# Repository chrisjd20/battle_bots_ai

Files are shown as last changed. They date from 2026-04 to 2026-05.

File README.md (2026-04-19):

# battle_bots_ai

Monorepo for **Plastic Antweight** combat robots (about **1 lb / 454 g or less**) and related work aligned with **SPARC** (Standardized Procedures for the Advancement of Robotic Combat). It holds software, PCB design, mechanical/CAD, 3D-printed parts, and docs for **multiple** bots and battle-bot accessories—not a single project.

## PCB design

**KiCad** is used for all PCB work. Shared footprints/symbols can live under `shared/kicad-libraries/`; per-bot or per-accessory boards sit under `bots/<name>/` or `accessories/<name>/` (often in a `pcb/` subfolder as projects grow).

`launch.sh` can open a KiCad project when present (see script for the expected path).

## KiCad + AI setup

- MCP config: `.cursor/mcp.json` (server name `kicad`)
- Launcher: `./launch.sh` (auto-detects one project, or pass explicit `.kicad_pro`)
- Workflow guide: `docs/hardware-workflow.md`
- Fabrication output location: `fab/`

Quick commands (after a KiCad project exists):

```bash
./launch.sh --check path/to/project.kicad_pro
kicad-cli sch erc path/to/project.kicad_sch
kicad-cli pcb drc path/to/project.kicad_pcb
```

## Mechanical CAD + AI setup

- Primary tooling: `FreeCAD` (GUI) + `build123d`/`CadQuery` (Python source)
- CAD tool bootstrap: `./shared/software-tools/cad/bootstrap.sh`
- MCP config: `.cursor/mcp.json` (server name `cad`)
- CAD workflow notes: `shared/software-tools/cad/README.md`

Quick commands:

```bash
./shared/software-tools/cad/bootstrap.sh
.venv-cad/bin/python bots/flipping-cool/cad/src/baseline_layout.py
```

## Repo layout (starter)

| Path | Purpose |
|---|---|
| `bots/` | One folder per robot |
| `accessories/` | Tools, jigs, side projects, non-robot-specific hardware |
| `shared/kicad-libraries/` | Reusable KiCad symbols, footprints, 3D models |
| `shared/cad-templates/` | Reusable CAD starter files or templates |
| `shared/software-tools/` | Shared scripts, utilities, or small tools |
| `docs/reference/` | Rules, datasheets summaries, reference notes |
| `docs/build-notes/` | Build logs, BOMs, assembly notes |

Individual projects may add subfolders such as `pcb/`, `firmware/`, `software/`, `cad/`, `prints/`, and `docs/` as needed.

## Other docs

- Design notes and concepts: keep them inside each bot's `docs/` folder (example: `bots/flipping-cool/docs/`).

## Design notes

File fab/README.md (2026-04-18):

# Fabrication Outputs

Use this folder for generated manufacturing artifacts, organized per project:

- `fab/<project>/gerber/`
- `fab/<project>/drill/`
- `fab/<project>/position/`
- `fab/<project>/bom/`

Guidelines:

- Keep generated outputs separate from source KiCad files.
- Regenerate outputs from current source before release/manufacturing.
- Include a short note per release with generation date, source project path, and tool versions.

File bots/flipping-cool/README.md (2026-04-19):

# Flipping Cool

This is the first robot project in this monorepo.

## Project name

Current name: `flipping-cool`.

Additional high level details in bots/flipping-cool/BATTLE_BOT1.md

## Scope

- `pcb/`: KiCad project files and board-related outputs
- `firmware/`: Embedded code for ESC, receiver, sensors, or control
- `software/`: Simulation, tooling, telemetry, or host-side logic
- `cad/`: Mechanical CAD sources
- `prints/`: 3D print models and slicing notes
- `docs/`: Build notes, BOM, test logs, and design decisions

## Key docs

- `BATTLE_BOT1.md`: high-level concept and weight-budget direction
- `docs/BOM.md`: v1 baseline parts lock, mechanical standards, and immediate
  next steps
- `cad/README.md`: script-first mechanical CAD generation workflow

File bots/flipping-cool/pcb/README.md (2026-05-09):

# Flipping Cool Rev B PCB

This KiCad project is now the active Rev B integration target for
`flipping-cool`. Rev A remains the historical receiver-driven baseline in the
older schematic sheets and docs; Rev B is the aggressive single-board control
and power architecture.

## Rev B Intent

Rev B integrates the electronics that make sense to put on the robot PCB:

- ESP32-S3-WROOM-1 module for firmware, BLE alternate control, telemetry, ADC
  rail sensing, status LEDs, I2C, and CRSF experiments.
- Board-generated `SERVO_6V` rail with a 5.5 A minimum target for receiver and
  weapon servo loads.
- Board-generated `AUX_3V3` rail for MCU, sensors, status, and debug logic.
- Hardware authority selection using the mandatory user-facing
  `SAFE / RX_DIRECT / MCU_CONTROL` switch.
- Receiver-priority PWM routing through hardware mux footprints so
  `RX_DIRECT` can bypass an unpowered or failed MCU.
- Matek receiver interface, optional CRSF UART, WEKA-native ESC power/PWM
  interface, motor/servo harness connectors, ADC dividers, debug headers, I2C,
  and status LEDs.

These remain off-board by design: motors, weapon servos, battery pack, WEKA
ESC, and Matek receiver.

## Active Artifacts

- `build_rev_b_pcb.py`: reproducible Rev B PCB/fab generator.
- `flipping-cool.kicad_pcb`: generated Rev B active board target, about
  `120 x 100 mm`, 4 copper layers.
- `fab_rev_b/`: generated Gerbers, drill, position CSV, STEP, renders, ZIP,
  and DRC report.
- `../docs/rev_b_architecture.md`: Rev B architecture and bench validation
  contract.

Run the generator from the repo root:

```bash
python3 bots/flipping-cool/pcb/build_rev_b_pcb.py
```

Run PCB DRC:

```bash
kicad-cli pcb drc bots/flipping-cool/pcb/flipping-cool.kicad_pcb \
  --output bots/flipping-cool/pcb/fab_rev_b/flipping-cool-rev-b-drc.rpt \
  --format report
```

## Current Validation Status

Rev B is **not yet print-ready**. The generated board/fab package exists, but
KiCad DRC is still failing in `fab_rev_b/flipping-cool-rev-b-drc.rpt`.

Current blocker class:

- Generated routing still needs hand/interactive cleanup around the ESP32-S3,
  switch/mux cluster, headers, and high-current rails.
- The schematic intent and board architecture are present, but PCB DRC must be
  driven to zero errors before ordering.

Acceptance remains:

- ERC: zero errors.
- PCB DRC: zero errors and zero required unconnected items.
- Rev B footprints present for MCU, regulators, mode switch, muxes, receiver,
  CRSF, WEKA interfaces, servo outputs, sensing, debug, I2C, and status.
- Fab ZIP regenerated only after DRC is clean.

Do not fabricate Rev B until DRC passes.

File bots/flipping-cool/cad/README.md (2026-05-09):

# Flipping Cool CAD

This folder contains the mechanical source files for `flipping-cool`.

## Source of truth

- `src/*.py` parametric scripts are authoritative.
- `generated/*` exports are derived outputs for inspection, sharing, and print
  prep.

## Current scripts

- `src/baseline_layout.py`: first-pass packaging envelopes from the BOM.
- `src/rev_a_layout.py`: Rev A assembly (motors, battery, servos, shafts).

## Generate outputs

From repo root:

```bash
.venv-cad/bin/python bots/flipping-cool/cad/src/baseline_layout.py
.venv-cad/bin/python bots/flipping-cool/cad/src/rev_a_layout.py
```

Generated files land in `bots/flipping-cool/cad/generated/`.

## View in FreeCAD

If you start FreeCAD from the application menu you get an **empty** "Unnamed"
document. You must **open the STEP file** or launch via the helper script.

From repo root:

```bash
./bots/flipping-cool/cad/view.sh
```

This runs `freecad` on `open_in_freecad.py`, which **imports the STEP with
`Part.read`** inside FreeCAD. Passing a `.step` path on the command line often
opens an empty document in the GUI, which is why the helper script exists.

If you still see a blank 3D view, check the **document tab** at the bottom:
select **`RevA_Layout`** (an older empty `Unnamed` tab may still be open).

**If the window is still blank:** use **File → Open** and choose:

`bots/flipping-cool/cad/generated/rev_a_assembly.step`

Then **View → Standard views → Fit all** (or press `V` then `B` in many
layouts).

**Windows FreeCAD + repo in WSL:** open the file via UNC path, for example
`\\wsl$\<distro>\home\...\battle_bots_ai\bots\flipping-cool\cad\generated\rev_a_assembly.step`
(substitute your distro name from `wsl -l -v`).

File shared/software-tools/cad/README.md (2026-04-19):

# CAD Automation Tooling

This folder holds the local CAD automation stack used by this repo.

## Tool choices

- `FreeCAD`: local GUI inspection and manual checks
- `build123d` / `CadQuery`: source-of-truth parametric modeling in Python
- `MCP (optional)`: tool entrypoints to run CAD scripts from Cursor

## Bootstrap

From repo root:

```bash
./shared/software-tools/cad/bootstrap.sh
```

This creates `.venv-cad` and installs packages from
`shared/software-tools/cad/requirements.txt`.

## Run a CAD model script

```bash
.venv-cad/bin/python bots/flipping-cool/cad/src/baseline_layout.py
```

## MCP server

The CAD MCP server lives at:

- `shared/software-tools/cad/cad_mcp_server.py`

When configured in `.cursor/mcp.json`, it exposes:

- `cad_environment`
- `run_cad_script`

## Source-of-truth policy

- Python CAD scripts in `cad/src/` are authoritative.
- Generated `STEP` / `STL` files under `cad/generated/` are derived artifacts.

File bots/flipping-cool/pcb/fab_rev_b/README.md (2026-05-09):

# Flipping Cool Rev B Fab Package

Generated by `../build_rev_b_pcb.py`.

Contents:

- Gerbers and drill files for the Rev B 4-layer integrated control/power PCB.
- Pick-and-place CSV for assembly-service review.
- STEP export and top/bottom renders for mechanical/visual checks.
- `flipping-cool-rev-b-fab.zip` archive of this folder.

Rev B target: about `120 x 100 mm`, ESP32-S3 controller, on-board `SERVO_6V`
and `AUX_3V3` regulators, receiver-priority hardware mode selection, external
Matek receiver, external WEKA ESC, external motors/servos/battery.

Status: this folder is a generated validation package, not an order-ready fab
release yet. Run KiCad DRC and do not fabricate until the report has zero
errors and zero required unconnected items.

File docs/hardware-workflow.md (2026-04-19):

# Hardware Workflow

This repo is configured as a reusable KiCad + AI workspace for multiple hardware projects.

For script-first mechanical CAD setup, see `docs/mechanical-workflow.md`.

## Current Status

- KiCad tooling is installed (`kicad`, `kicad-cli`, `pcbnew` import).
- Project-local MCP config exists at `.cursor/mcp.json`.
- `launch.sh` can auto-detect a single `*.kicad_pro` or accept an explicit project path.
- No `*.kicad_pro` file is currently tracked in this repo.

## Known Gaps

- Until a KiCad project file exists, ERC/DRC/export commands cannot run on this repo.
- Docker is referenced from Windows-side Docker Desktop but is not currently available inside this WSL distro.

## Intended Day-to-Day Flow

1. Create or open a KiCad project under `bots/<name>/...` or `accessories/<name>/...`.
2. Edit schematic, then run ERC.
3. Sync schematic to PCB.
4. Place components and route.
5. Run DRC.
6. Export fabrication outputs into `fab/<project>/`.

## Validation Commands

Use these from repo root after a project exists:

```bash
./launch.sh --check path/to/project.kicad_pro
./launch.sh path/to/project.kicad_pro
kicad-cli sch erc path/to/project.kicad_sch
kicad-cli pcb drc path/to/project.kicad_pcb
python3 -c "import pcbnew; print(pcbnew.GetBuildVersion())"
```

MCP smoke check:

```bash
LOG_LEVEL=info KICAD_PYTHON=/usr/bin/python3 PYTHONPATH=/usr/lib/python3/dist-packages timeout 8s node /home/admin/github/lora-low-power-surveillance/tools/KiCAD-MCP-Server/dist/index.js
```

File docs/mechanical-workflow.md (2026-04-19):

# Mechanical CAD Workflow

This repo uses a local, script-first CAD workflow for automation:

- `FreeCAD` for manual inspection and occasional direct edits
- `build123d` / `CadQuery` Python scripts as source of truth

## Current Status

- `freecad` installed via apt
- repo-local CAD virtualenv at `.venv-cad`
- CAD MCP server configured in `.cursor/mcp.json` as `cad`

## Source-of-truth policy

- Authoritative CAD source: `bots/<name>/cad/src/*.py`
- Derived artifacts: `bots/<name>/cad/generated/*.step`, `*.stl`

## Day-to-day flow

1. Update parametric script in `cad/src/`.
2. Generate outputs into `cad/generated/`.
3. Inspect geometry in FreeCAD.
4. Iterate dimensions and regenerate outputs.
5. Use stable geometry to finalize BOM, clearances, and then electrical layout.

## Validation commands

From repo root:

```bash
./shared/software-tools/cad/bootstrap.sh
.venv-cad/bin/python bots/flipping-cool/cad/src/baseline_layout.py
freecad --version
```

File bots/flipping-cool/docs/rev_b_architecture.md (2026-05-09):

# Flipping Cool Rev B Architecture And Build Validation

## Board Class

Rev B is a 4-layer integrated control/power PCB targeting about
`120 x 100 mm`. It is assembly-service oriented rather than hand-assembly
first. The current generator is `../pcb/build_rev_b_pcb.py`.

## Off-Board Boundary

The PCB is not trying to embed the physical actuators or proven high-current
ESC module. These stay off-board:

- 2S LiHV battery pack.
- Four drive motors.
- Two weapon servos.
- External WEKA dual brushed ESC.
- External Matek ELRS-R24-P6 receiver.

## Power Tree

| Net | Source | Loads |
| --- | --- | --- |
| `VBAT_RAW` | Battery `J1` before link | Removable positive link only |
| `VBAT_SW` | Link output `J2` | WEKA power, regulators, TVS, LED, ADC divider |
| `SERVO_6V` | `U20` 6 V buck, 5.5 A minimum target | Receiver branch and servo outputs |
| `RX_6V` | Filtered `SERVO_6V` branch | Matek receiver and CRSF header power |
| `AUX_3V3` | `U30` dedicated buck | ESP32-S3, muxes, status, I2C, ADC network |
| `GND_PWR` | Common board return | Battery, ESC, regulators, receiver, MCU, servos |

Protection and observability:

- Removable link is the only intended `VBAT_RAW` to `VBAT_SW` bridge.
- `D1` clamps `VBAT_SW` transients to `GND_PWR`.
- `F1` protects auxiliary 3.3 V buck input branch.
- `TP1`-`TP6` expose primary rails.
- `R40`-`R45` sense `VBAT_SW`, `SERVO_6V`, and `RX_6V`.

## Control Authority Model

The mode switch is mandatory and user-visible:

| State | Hardware authority | MCU requirement | Intended use |
| --- | --- | --- | --- |
| `SAFE` | Outputs safe/inactive | None | Bench, pits, setup |
| `RX_DIRECT` | Receiver PWM direct path | MCU may be absent | Match fallback and first-drive validation |
| `MCU_CONTROL` | ESP32-S3 PWM path | MCU powered and healthy | BLE alternate control, telemetry-aware behavior |

Receiver-priority rule: Rev B must remain controllable in `RX_DIRECT` even
with the MCU unpowered or failed.

## Interface Pin Maps

### `J10` Matek Receiver PWM

| Pin | Net |
| ---: | --- |
| 1 | `GND_PWR` |
| 2 | `RX_6V` |
| 3 | `RX_PWM_DRIVE_LEFT` |
| 4 | `RX_PWM_DRIVE_RIGHT` |
| 5 | `RX_PWM_WEAPON_FR` |
| 6 | `RX_PWM_WEAPON_LR` |
| 7 | `PWM_RX_SPARE1` |
| 8 | `PWM_RX_SPARE2` |

### `J11` CRSF UART

| Pin | Net |
| ---: | --- |
| 1 | `GND_PWR` |
| 2 | `RX_6V` |
| 3 | `CRSF_RX_FROM_RX` |
| 4 | `CRSF_TX_TO_RX` |

### `J21` WEKA PWM

| Pin | Net |
| ---: | --- |
| 1 | `GND_PWR` |
| 2 | `WEKA_5V_BEC_NC_MON` |
| 3 | `PWM_DRIVE_LEFT` |
| 4 | `PWM_DRIVE_RIGHT` |

### Servo Outputs

`J30` and `J31` are weapon outputs; `J32` and `J33` are spare 6 V PWM outputs.

| Pin | Net |
| ---: | --- |
| 1 | `GND_PWR` |
| 2 | `SERVO_6V` |
| 3 | channel PWM |

## Bench Acceptance Checklist

- Verify no battery continuity from `VBAT_RAW` to `VBAT_SW` with link removed.
- Verify `VBAT_SW` appears only after link insertion.
- Load-test `SERVO_6V` across the expected servo/radio envelope, including
  sustained current and transient servo-load pulses.
- Load-test `AUX_3V3` with MCU, status, I2C, and mux loads.
- Confirm startup/shutdown does not inject unsafe pulses into WEKA or servo
  outputs.
- Confirm `SAFE` output inactivity.
- Confirm `RX_DIRECT` drives ESC and weapon outputs with MCU unpowered.
- Confirm `MCU_CONTROL` gives the ESP32-S3 authority only when physically
  selected.
- Confirm BLE command path is ignored outside `MCU_CONTROL`.
- Confirm CRSF pins are reachable by the MCU without breaking PWM mode.
- Confirm rail ADC readings track measured bench voltages.

## Current CAD Validation

The current Rev B board generator creates footprints, placement, routes,
Gerbers, drill, position CSV, STEP, renders, and DRC report. It is **not
print-ready** yet because KiCad PCB DRC is still failing. The next PCB task is
interactive routing cleanup or a stronger router pass until the DRC report has
zero errors and zero required unconnected items.

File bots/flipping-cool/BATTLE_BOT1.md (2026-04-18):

# BATTLE_BOT1

This is the `1 lb / 454 g` optimized version of the concept.

The earlier direction had the right idea, but it was not fully weight-optimized yet. At this class, the winning bot is not a tiny high-throw launcher. It is a **low, compact, durable four-way control flipper** that can attack from any side, self-right instantly, and keep working after repeated hits.

This plan assumes a normal plastic-ant interpretation: plastic structure and armor, with normal motors, electronics, shafts, and fasteners still allowed. If your event is stricter, re-check materials before locking anything in.

## 1 lb Verdict

The original concept was close, but not truly optimized for `454 g` because it still spent too much complexity on independence and not enough on packaging.

The biggest changes for a serious `1 lb` version are:

- stop thinking in terms of a huge flip
- optimize for **ground game, control, and recovery**
- pair opposite weapon faces into **2 weapon axes**
- build around a strict weight budget from day one
- keep electronics simple and proven for `v1`

## The Best 1 lb Version

If I were optimizing this concept specifically for `1 lb`, I would build a **chamfered-square tumbleweed control flipper**:

- four active flipper faces
- four short corner drive pods
- four-wheel drive
- two central weapon servos
- each servo drives one pair of opposite flippers

So you still keep the four-sided identity, but you stop paying the full weight and power penalty of four independent weapon channels.

That is the biggest improvement.

## Why 2 Weapon Axes Beats 4 Independent Flippers

At `1 lb`, full independence sounds cooler than it is useful.

Two paired axes is better because it:

- saves weight over four weapon servos
- reduces BEC load and brownout risk
- keeps the center of the robot available for battery and wiring
- simplifies driving under match stress
- still lets the bot attack and self-right from any orientation

Control layout should be:

- standard tank drive
- one momentary input for `front + rear`
- one momentary input for `left + right`

That is much more realistic in an actual fight than four separate weapon controls.

## Shape And Packaging

Do **not** build a true regular octagon.

Build a **square with clipped corners**:

- four long weapon faces
- four short corner pods for wheels and impact protection
- slightly crowned top and bottom so the robot rolls into a recoverable attitude instead of landing dead-flat

Target envelope:

- about `90 to 95 mm` square overall
- about `26 to 30 mm` tall
- as low as possible with the battery centered near the floor

The robot should look low and dense, not dramatic or tall.

## Weapon Geometry

Each active face should be a **low scoop-flipper**, not a vertical door.

The right motion is:

- closed position already forms a shallow wedge
- open position travels only far enough to lift, upset, and roll an opponent
- fast reset matters more than total throw

Think:

- **snap-lifter**
- **control flipper**
- **wheel-pop and turnover tool**

Not:

- catapult
- big theatrical launch

## Weapon Mechanism

The `1 lb` optimized mechanism is:

- `2x` stronger metal-gear weapon servos in the center
- `2x` lightweight cross-shafts, one per axis
- short mirrored bellcranks or pushrods to each pair of opposite flippers
- hard mechanical stops in both directions

Very important details:

- never drive the flipper plate directly from a servo horn
- keep the linkage short and protected
- set the closed position slightly **over-center**
- make impacts load the chassis stop, not the servo gears

At this scale, servo failures come from shock and back-driving more often than from lack of nominal torque.

## Drive System

For this concept, I would keep `4WD`.

Why:

- the corners are the cleanest place to put wheels
- you preserve all four long weapon faces
- the robot keeps traction no matter which side becomes the front

Recommended direction:

- `4x` small brushed gearmotors in the corner pods
- left pair electrically tied together
- right pair electrically tied together
- normal tank drive from the radio point of view

Good target behavior:

- quick acceleration
- moderate top speed
- strong pushing, not drag-race speed

If you must save weight, cut body mass before cutting drive traction.

## Electronics

Keep `v1` boring and reliable:

- `ELRS` receiver
- `dual brushed ESC` or equivalent two-channel brushed drive setup
- `2S LiPo/LiHV`
- direct receiver control for the two weapon axes

Do **not** start with:

- a custom PCB
- a microcontroller dependency
- fancy automation that the robot needs in order to function

You can always add smart features later, like:

- self-right macro
- servo pulse shaping
- orientation-aware mixing

But the first robot should be able to win without any of that.

## Power Strategy

The biggest electrical threat is not drive current.

It is **weapon-servo brownout and reset behavior**.

Design around that from the start:

- use an external servo power rail or BEC that can actually feed the weapon servos
- do not rely on a weak ESC BEC for the whole robot
- keep receiver power clean
- add capacitance near the receiver/BEC rail

Plain-English rule:

**If four corners drive and two weapon axes move at the same time, the radio must stay alive.**

## Realistic Weight Budget

Build to this budget, not to vibes:

- chassis tub, top shell, bottom shell, corner pods: `115 g max`
- four flipper plates, hinge hardware, linkage arms: `46 g max`
- two weapon servos: `42 g max`
- four drive motors: `52 g max`
- wheels, tires, hubs: `28 g max`
- battery: `35 g max`
- drive ESC: `15 g max`
- receiver: `3 g max`
- external BEC, capacitor, small power board: `18 g max`
- wiring, connectors, switch: `20 g max`
- bolts, nuts, axles, retainers: `30 g max`
- reserve for tuning and surprises: `50 g`

Total target: `454 g`

That reserve is intentional. A `1 lb` bot with no reserve is not optimized. It is just unfinished.

## Material Strategy

If `PETG` is what you have, use it carefully rather than using it everywhere at the same thickness.

Best approach:

- printed chassis tub in `PETG` or tougher plastic if available
- printed shell designed with ribs, not just thick walls
- flipper faces in `polycarbonate` sheet if your rules allow it
- otherwise printed flippers with replaceable leading lips
- metal hinge pins and fasteners if the rules permit them

Make these parts modular and replaceable:

- flipper faces
- corner guards
- skid/lip inserts
- linkage tabs

Those are consumables.

## Layout That Actually Fits

Top-down, the packaging should work like this:

- battery in the center and as low as possible
- receiver tucked above or beside the battery
- drive ESC close to the battery
- BEC and capacitor near receiver power entry
- two weapon servos centered on the two main axes
- cross-shafts running front/rear and left/right
- drive motors in the four corner pods

That keeps:

- mass centralized
- weapon linkages short
- the outer shell free to absorb impacts

## What To Avoid

Avoid these completely in the `1 lb` version:

- a true regular octagon
- `CO2` or any pneumatic system
- four fully independent weapon controls
- direct-driving a plate from the servo spline
- exposed servo arms
- tall flipper doors
- custom electronics as the first milestone
- powering weapon servos from a weak built-in BEC

Height is a trap on control bots. Stay low.

## Build Priorities

Build in this order:

1. driving chassis that makes weight
2. one weapon axis with hard stops
3. second weapon axis
4. replaceable lips and corner armor
5. radio mapping and self-right testing

Do not design the whole robot around version-2 electronics before the version-1 chassis survives impacts.

## Final 1 lb Spec

If I were locking the design today, I would commit to this:

- chamfered-square chassis
- four low scoop-flippers
- four corner drive wheels
- two central weapon servos
- opposite sides paired into two weapon axes
- no custom PCB in `v1`
- low-profile control-flipper tuning, not giant-launch tuning
- hard weight budget with at least `40 to 50 g` reserved until late in the build

That is the version most optimized for `1 lb`: simpler, lighter, easier to package, easier to drive, and more likely to survive real matches.

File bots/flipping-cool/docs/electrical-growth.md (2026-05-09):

# Flipping Cool Rev B Electrical Integration

## What Changed From Rev A

Rev A was intentionally receiver-driven. Its growth headers were passive taps
for future telemetry and debug.

Rev B makes those growth ideas active board features:

- ESP32-S3 module is on the PCB.
- 6 V servo/radio regulation is on the PCB.
- 3.3 V MCU/sensor regulation is on the PCB.
- PWM authority is selected by hardware using `SAFE / RX_DIRECT / MCU_CONTROL`.
- CRSF, I2C, ADC sensing, status LEDs, boot/reset, and debug headers are placed
  instead of being future-only placeholders.

## Power Tree

`VBAT_RAW` enters from the 2S XT30 battery connector and reaches `VBAT_SW` only
through the removable positive link. `VBAT_SW` feeds:

- WEKA ESC power connector.
- `U20` 6 V buck stage for `SERVO_6V`.
- fused input to `U30` 3.3 V buck stage for `AUX_3V3`.
- TVS clamp, bulk capacitance, power LED, and test points.

`SERVO_6V` powers receiver and servo outputs. `RX_6V` is the filtered receiver
branch. `AUX_3V3` powers MCU, muxes, sensors, status, and debug logic.

## Control Authority

Rev B does not let firmware silently take over the robot. The physical mode
switch is the contract:

| Switch | Required behavior |
| --- | --- |
| `SAFE` | Outputs inactive/safe. Used for bench setup and pit handling. |
| `RX_DIRECT` | Matek receiver PWM drives the ESC and weapon outputs without MCU dependency. |
| `MCU_CONTROL` | ESP32-S3 path may command outputs; BLE alternate control is allowed only here. |

The default safety policy is receiver-priority. If the MCU is unpowered or has
failed, `RX_DIRECT` must still be drivable once the receiver and 6 V rail are
alive.

## Integrated Interfaces

- `J10`: Matek ELRS-R24-P6 PWM receiver header.
- `J11`: optional CRSF UART between receiver and MCU.
- `J20`: WEKA switched battery input.
- `J21`: WEKA PWM harness; WEKA 5 V BEC remains monitor/no-connect.
- `J23`-`J26`: motor harness solder pads for off-board motors.
- `J30`/`J31`: weapon servo PWM outputs.
- `J32`/`J33`: spare 6 V PWM outputs.
- `J44`: pit/debug rail and comms header.
- `J46`-`J48`: MCU power/comms, signal, ADC, and status debug headers.
- `J49`: I2C sensor connector.

## Validation Gate

Rev B is not allowed to be ordered until:

- KiCad ERC is zero-error for the Rev B schematic representation.
- KiCad PCB DRC is zero-error and required nets have zero unconnected items.
- `SAFE`, `RX_DIRECT`, and `MCU_CONTROL` are bench-tested with the MCU powered
  and unpowered.
- 6 V and 3.3 V rails are load-tested for regulation, startup, shutdown,
  brownout observability, and thermal sanity.
- BLE alternate control is confirmed to be ignored unless `MCU_CONTROL` is
  physically selected.

Current status: the Rev B generated PCB/fab package exists, but DRC is failing
and must be cleaned before fabrication.

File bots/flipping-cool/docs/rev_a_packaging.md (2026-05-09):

# Rev A Packaging Layout

This document summarizes the current packaging layout and dimensions based on the `cad/src/rev_a_layout.py` script.

## Frozen Dimensions (Rev A)
- **Robot Envelope**: 95.0 x 95.0 x 28.0 mm
- **Corner Chamfer**: 20.0 mm
- **Wheelbase**: 55.0 mm (distance between front and rear axles)
- **Track Width**: 75.0 mm (distance between left and right wheel centerlines)
- **Weapon Servo Positions**: Center-mounted beside the battery, offset by `~22mm` from center Y-axis. One faces front/rear flippers, one faces left/right flippers.
- **Weapon Cross-Shafts**: Lengths of `91.0 mm` on X and Y axes, clearing the chassis walls by 2mm per side. Height Z offset: 24mm (X-axis) and 20mm (Y-axis) to avoid crossing interference.

## Check Results
1. **Drive Pods**: The four Pololu N20 motors fit cleanly at the chamfered corners with standard 22mm wheels.
2. **Central Bay**: The GNB 450mAh 2S battery and two Savox servos physically fit inside the 95mm chassis without height violations.
3. **Weapon Linkages**: The cross-shafts are currently stacked at two different heights (Z=20mm and Z=24mm) so they do not intersect in the dead center. This forces the flipper bellcranks to have two different radii/geometries.

## Open Risks & Next Steps
- The weapon cross shafts cross in the center, so they must be stacked at different heights (currently Z=20 and Z=24). This requires designing two different linkage bellcranks.
- Need to finalize precise ESC and BEC placement in the remaining open space near the battery.
- Need to confirm mass of the 3D-printed chassis around these parts.

*See `cad/generated/rev_a_assembly.step` for the 3D export.*

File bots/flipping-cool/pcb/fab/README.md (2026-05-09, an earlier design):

# Flipping Cool Rev A Fab Package

Generated from `../flipping-cool.kicad_pcb` with KiCad CLI 9.0.7.

## Fabrication Files

- `gerbers/`: copper, mask, paste, silkscreen, edge cuts, and Gerber job file.
- `drill/`: separate PTH/NPTH Excellon drill files plus drill-map PDFs.
- `flipping-cool-pos.csv`: board pick-and-place position export.
- `flipping-cool-top.png` / `flipping-cool-bottom.png`: quick visual renders.
- `reports/`: ERC and DRC reports used for release verification.

## Verification

- ERC: `0` errors, `0` warnings.
- PCB DRC, error severity: `0` violations, `0` unconnected pads.
- PCB DRC, all severities: one non-blocking `silk_over_copper` warning from
  the official KiCad `J22` wire strain-relief footprint. Gerbers were exported
  with `--subtract-soldermask`, so that silkscreen is clipped cleanly.

The schematic-parity report is included for traceability. Its warnings are for
unplaced optional growth/test footprints and extra mechanical mounting holes;
they are not required for the base receiver-driven bot PCB.

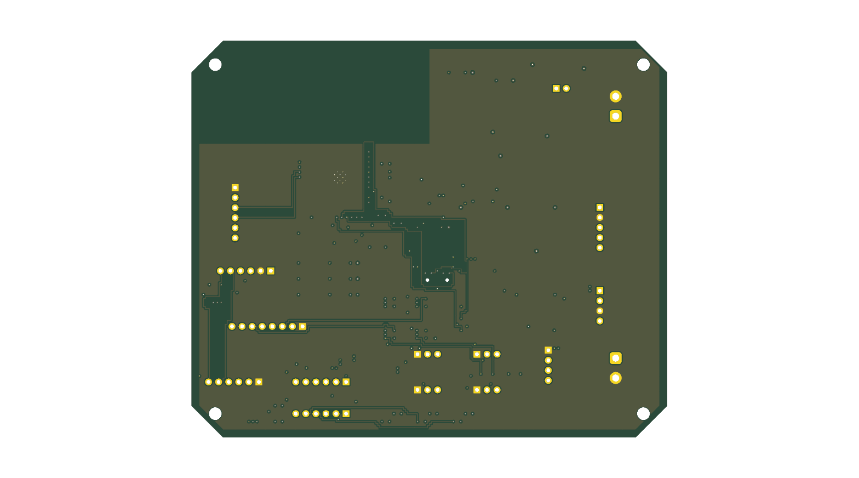
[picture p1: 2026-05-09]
bots/flipping-cool/pcb/fab_rev_b/flipping-cool-rev-b-bottom.png

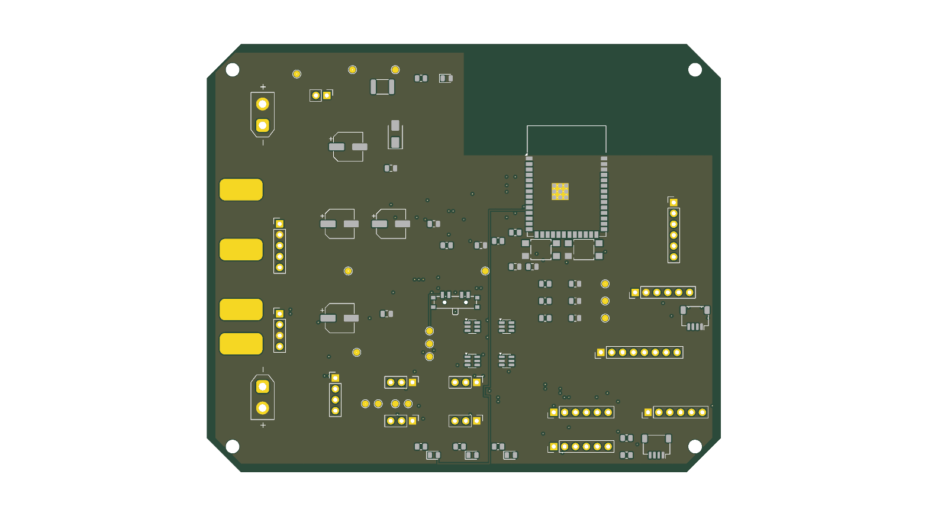
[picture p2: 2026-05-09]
bots/flipping-cool/pcb/fab_rev_b/flipping-cool-rev-b-top.png

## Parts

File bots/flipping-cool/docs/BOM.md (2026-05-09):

# Flipping Cool Rev B BOM Baseline

## Purpose

This BOM tracks the Rev B max-integration electrical target while preserving
the Rev A mechanical/off-board assumptions. Rev B moves control, regulation,
sensing, status, and hardware authority selection onto one PCB.

## Off-Board By Design

- Battery: GNB 2S 450 mAh HV 80C XT30 pack, `GNB4502S80AHV`.
- Drive motors: 4x Pololu 75:1 Micro Metal Gearmotor HPCB 6V, item `3064`.
- Wheels: 4x BBB 22 mm antweight wheels.
- Weapon servos: 2x Savox SH-0255MG+.
- Receiver: Matek ELRS-R24-P6 PWM receiver.
- Drive ESC: external WEKA dual brushed ESC.

## On-Board Rev B Electronics

| Ref | Qty | Function | Rev B baseline |
| --- | ---: | --- | --- |
| `U10` | 1 | Main controller | ESP32-S3-WROOM-1 module |
| `U20` | 1 | Servo/radio regulator | Board-mounted 6 V buck stage, 5.5 A minimum target |
| `U30` | 1 | Logic regulator | Dedicated 3.3 V buck stage for MCU/sensors/status |
| `SW1` | 1 | Control authority | 3-position `SAFE / RX_DIRECT / MCU_CONTROL` switch |
| `U40`-`U43` | 4 | PWM source select | SPDT signal switch/mux footprints for drive L/R and weapon FR/LR |
| `J10` | 1 | Receiver | Matek PWM receiver header |
| `J11` | 1 | CRSF | JST-SH 4-pin UART experiment port |
| `J20` | 1 | ESC power | WEKA power XT30 interface |
| `J21` | 1 | ESC PWM | WEKA-native PWM header; WEKA 5 V BEC is monitor/no-connect |
| `J23`-`J26` | 4 | Motor harness | High-current solder pads for off-board motor wiring |
| `J30`-`J33` | 4 | Servo outputs | Weapon FR/LR plus two spare 6 V PWM outputs |
| `J44` | 1 | Pit/debug | Rails and CRSF access |
| `J46`-`J48` | 3 | MCU/debug taps | Power/comms, signal taps, sense/status |
| `J49` | 1 | I2C | STEMMA QT/Qwiic-order connector |
| `D50`-`D52` | 3 | Status | On-board RGB-style status indicator channels |

## Power And Protection

- `VBAT_RAW` enters at `J1` and reaches `VBAT_SW` only through the removable
  positive link at `J2`.
- `VBAT_SW` feeds WEKA power, the 6 V buck stage, the fused 3.3 V buck input,
  TVS clamp `D1`, bulk capacitance, and measurement points.
- `SERVO_6V` is generated on-board and powers the Matek receiver and servo
  outputs.
- `RX_6V` is a filtered branch of `SERVO_6V` for receiver power.
- `AUX_3V3` is generated by a dedicated buck and powers the MCU, muxes, status,
  I2C, and sensing network.
- `R40`-`R45` implement 100 k / 47 k rail dividers for `ADC_VBAT`,
  `ADC_SERVO_6V`, and `ADC_RX_6V`.
- `R46`/`R47` are DNP 4.7 k I2C pull-ups unless the sensor stack needs them.

## Control Contract

- `SAFE`: outputs must be forced safe by hardware/firmware policy before bench
  load testing.
- `RX_DIRECT`: receiver PWM remains the hardware-priority path and must work
  with the MCU unpowered or failed.
- `MCU_CONTROL`: ESP32-S3 may command PWM outputs and BLE alternate control,
  but only when the physical switch selects this state.

## Fabrication Status

The Rev B BOM and PCB artifacts exist, but the current generated PCB is not yet
fabrication-ready because PCB DRC is failing. Treat `pcb/fab_rev_b/` as a
validation package until `flipping-cool-rev-b-drc.rpt` reports zero errors.

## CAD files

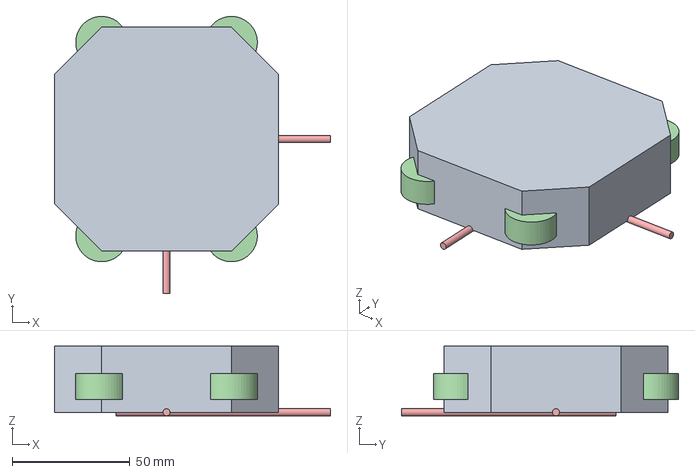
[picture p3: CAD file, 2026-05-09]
bots/flipping-cool/cad/generated/rev_a_assembly.step
117.0 x 117.5 x 29.5 mm

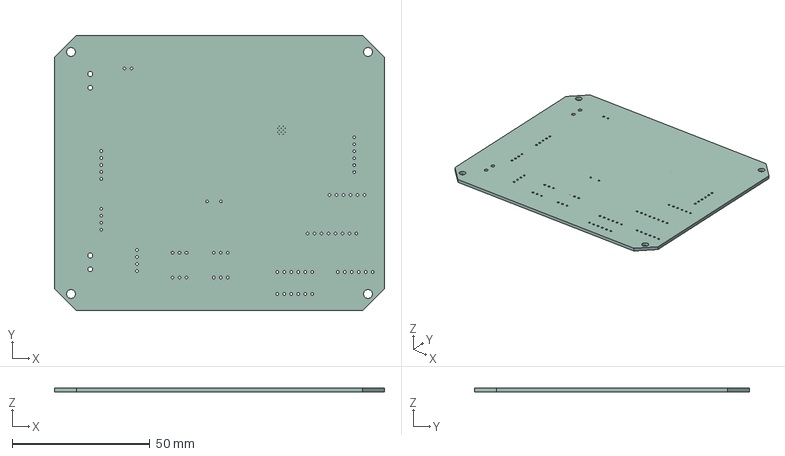
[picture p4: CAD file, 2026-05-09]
bots/flipping-cool/pcb/fab_rev_b/flipping-cool-rev-b.step
120.0 x 100.0 x 1.51 mm

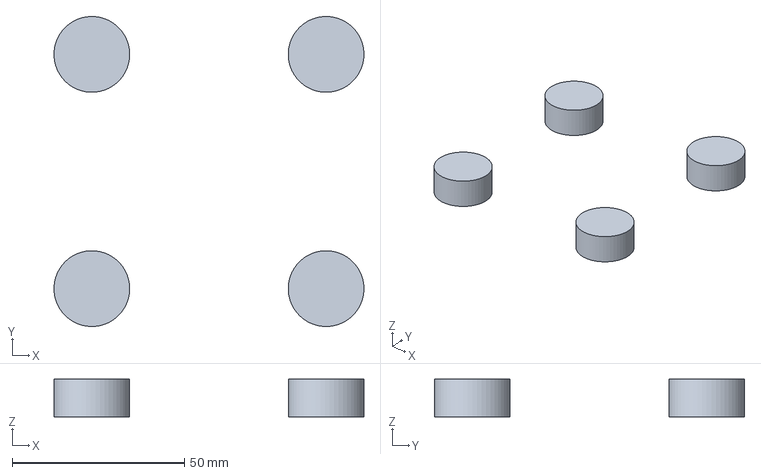
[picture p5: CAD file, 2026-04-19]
bots/flipping-cool/cad/generated/wheel_envelopes.step
90.0 x 90.0 x 11.0 mm

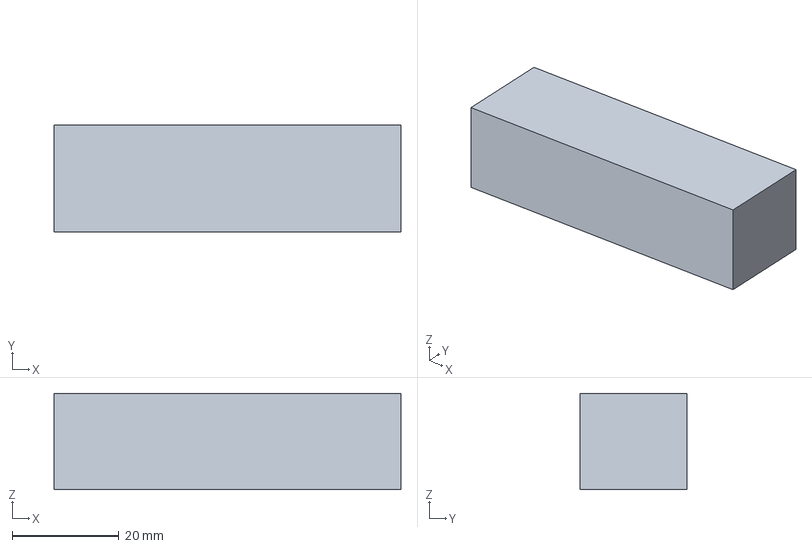
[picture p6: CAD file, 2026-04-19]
bots/flipping-cool/cad/generated/battery_envelope.step
65.0 x 20.0 x 18.0 mm

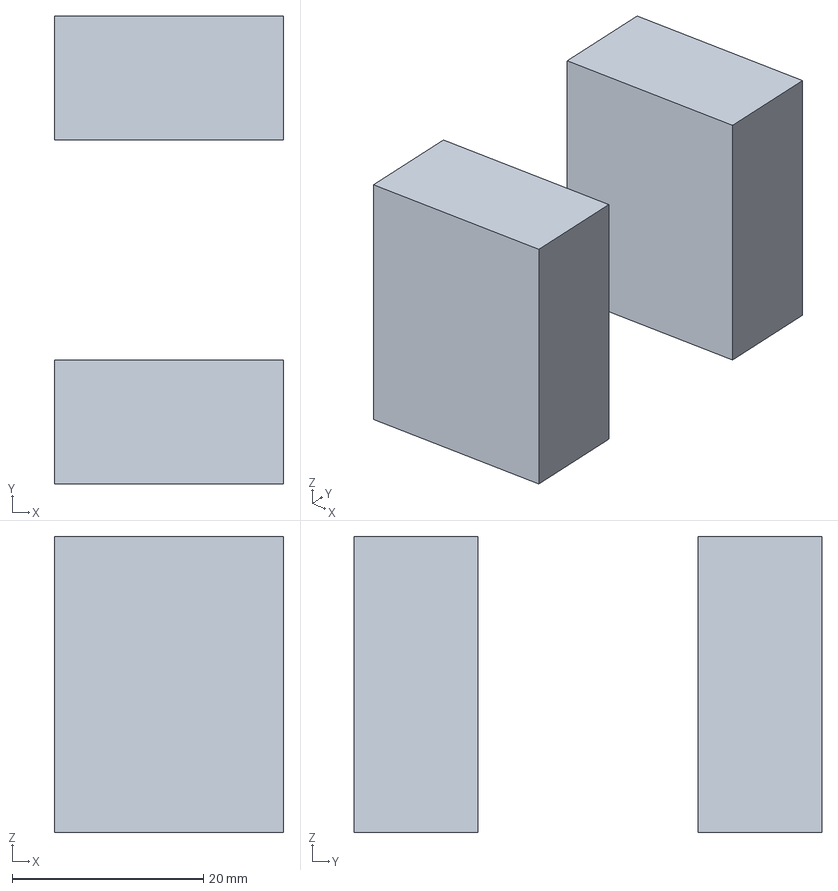
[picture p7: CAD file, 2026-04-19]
bots/flipping-cool/cad/generated/servo_envelopes.step
24.0 x 49.0 x 31.0 mm

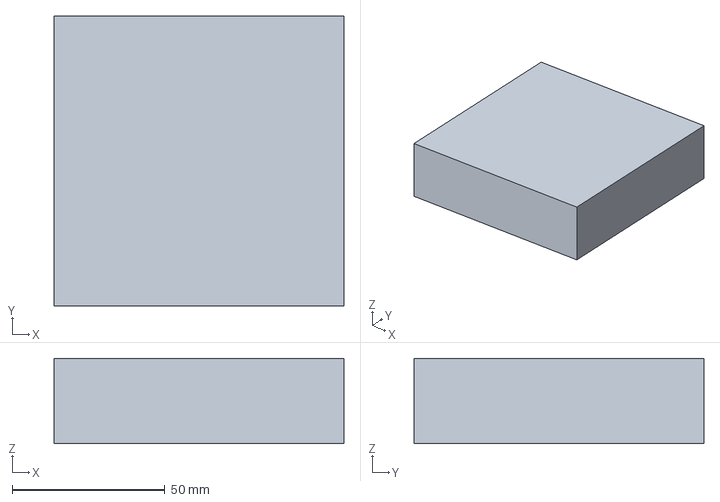
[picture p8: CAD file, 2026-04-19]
bots/flipping-cool/cad/generated/chassis_envelope.step
95.0 x 95.0 x 28.0 mm

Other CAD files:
bots/flipping-cool/cad/generated/chassis_envelope.stl
bots/flipping-cool/cad/generated/rev_a_assembly.stl

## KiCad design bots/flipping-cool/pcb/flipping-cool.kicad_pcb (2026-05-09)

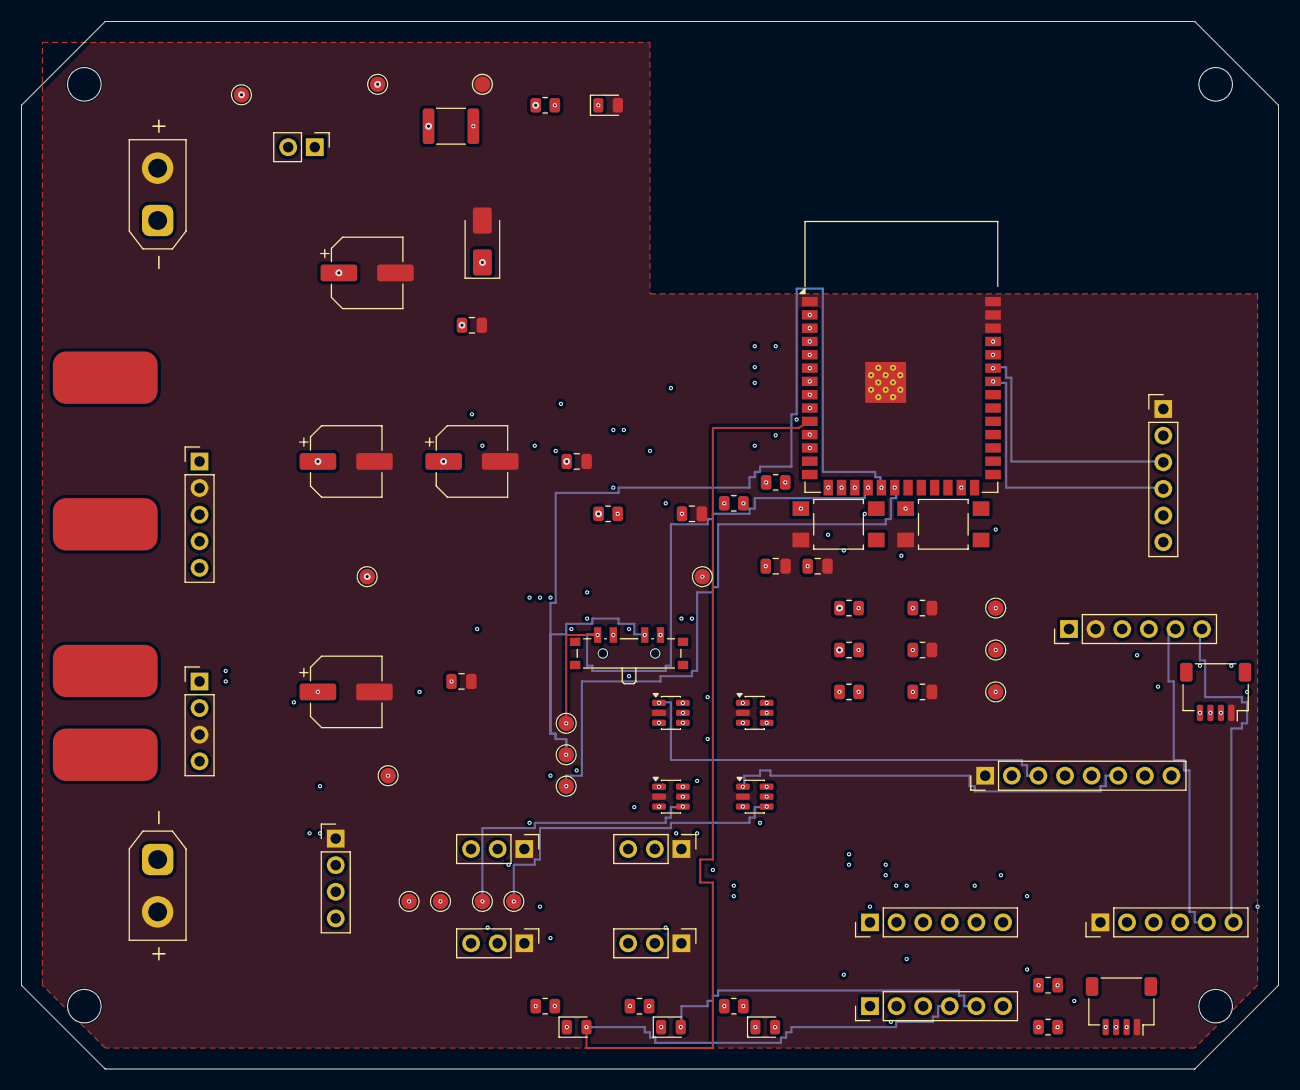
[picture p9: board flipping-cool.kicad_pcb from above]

Board: 4 copper layers, 120.0 x 100.0 mm, 81 parts (0 on the bottom side), 42 nets.

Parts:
C1: 470uF_16V_LOW_ESR; CP_Elec_6.3x7.7
C2: 10uF_16V; C_0805_2012Metric
C10: 10uF_3V3_LOCAL; C_0805_2012Metric
C11: 100nF_3V3_LOCAL; C_0805_2012Metric
C20: 1000uF_10V_SERVO; CP_Elec_6.3x7.7
C21: 100uF_10V; CP_Elec_6.3x7.7
C22: 10uF_10V; C_0805_2012Metric
C23: 22uF_RX; C_0805_2012Metric
C30: 47uF_6V3; CP_Elec_6.3x7.7
C31: 10uF_6V3; C_0805_2012Metric
D1: SMBJ12CA_TVS; D_SMA
D2: PWR_LED; LED_0805_2012Metric
D50, D51, D52: STATUS_LED; LED_0805_2012Metric
F1: PTC_500mA_AUX; Fuse_1812_4532Metric
FB1: RX_6V_FILTER; R_0805_2012Metric
J1: BATTERY_XT30; AMASS_XT30UPB-F_1x02_P5.0mm_Vertical
J2: REMOVE_LINK_VBAT; PinHeader_1x02_P2.54mm_Vertical
J10: MATEK_ELRS_R24_P6_PWM; PinHeader_1x08_P2.54mm_Vertical
J11: CRSF_UART; JST_SH_SM04B-SRSS-TB_1x04-1MP_P1.00mm_Horizontal
J12: UART_PROGRAM; PinHeader_1x06_P2.54mm_Vertical
J20: WEKA_POWER_XT30; AMASS_XT30UPB-F_1x02_P5.0mm_Vertical
J21: WEKA_PWM; PinHeader_1x04_P2.54mm_Vertical
J23: WEKA_M1A; SolderWirePad_1x01_SMD_5x10mm
J24: WEKA_M1B; SolderWirePad_1x01_SMD_5x10mm
J25: WEKA_M2A; SolderWirePad_1x01_SMD_5x10mm
J26: WEKA_M2B; SolderWirePad_1x01_SMD_5x10mm
J30: PWM_WEAPON_FR_SERVO; PinHeader_1x03_P2.54mm_Vertical
J31: PWM_WEAPON_LR_SERVO; PinHeader_1x03_P2.54mm_Vertical
J32: PWM_SERVO_SPARE1_SERVO; PinHeader_1x03_P2.54mm_Vertical
J33: PWM_SERVO_SPARE2_SERVO; PinHeader_1x03_P2.54mm_Vertical
J44: PIT_DEBUG; PinHeader_1x06_P2.54mm_Vertical
J46: MCU_POWER_COMMS; PinHeader_1x06_P2.54mm_Vertical
J47: MCU_SIGNAL_TAPS; PinHeader_1x06_P2.54mm_Vertical
J48: MCU_SENSE_STATUS; PinHeader_1x06_P2.54mm_Vertical
J49: I2C_STEMMA_QT; JST_SH_SM04B-SRSS-TB_1x04-1MP_P1.00mm_Horizontal
MH1, MH2, MH3, MH4: M3 mounting; MountingHole_3.2mm_M3
R1: 2.2k; R_0805_2012Metric
R10: 10k_EN_PULLUP; R_0805_2012Metric
R11: 10k_BOOT_PULLUP; R_0805_2012Metric
R40, R42, R44: 100k; R_0805_2012Metric
R41, R43, R45: 47k; R_0805_2012Metric
R46, R47: 4.7k_DNP; R_0805_2012Metric
R50, R51, R52: 330; R_0805_2012Metric
SW1: MODE_SAFE_RX_MCU; SW_SP3T_PCM13
SW2: RESET; SW_SPST_TL3305B
SW3: BOOT; SW_SPST_TL3305B
TP1: VBAT_RAW; TestPoint_Pad_D1.5mm
TP2: VBAT_SW; TestPoint_Pad_D1.5mm
TP3: GND; TestPoint_Pad_D1.5mm
TP4: SERVO_6V; TestPoint_Pad_D1.5mm
TP5: RX_6V; TestPoint_Pad_D1.5mm
TP6: AUX_3V3; TestPoint_Pad_D1.5mm
TP7: MODE_SAFE; TestPoint_Pad_D1.5mm
TP8: MODE_RX_DIRECT; TestPoint_Pad_D1.5mm
TP9: MODE_MCU_CONTROL; TestPoint_Pad_D1.5mm
TP10: ADC_VBAT; TestPoint_Pad_D1.5mm
TP11: ADC_SERVO_6V; TestPoint_Pad_D1.5mm
TP12: ADC_RX_6V; TestPoint_Pad_D1.5mm
TP13: PWM_DRIVE_LEFT; TestPoint_Pad_D1.5mm
TP14: PWM_DRIVE_RIGHT; TestPoint_Pad_D1.5mm
TP15: PWM_WEAPON_FR; TestPoint_Pad_D1.5mm
TP16: PWM_WEAPON_LR; TestPoint_Pad_D1.5mm
U10: ESP32-S3-WROOM-1
U20: 6V_BUCK_5.5A_MIN; PinHeader_1x05_P2.54mm_Vertical
U30: 3V3_BUCK_POL_D24V5F3; PinHeader_1x04_P2.54mm_Vertical
U40: SPDT_PWM_MUX_PWM_DRIVE_LEFT; SOT-23-6
U41: SPDT_PWM_MUX_PWM_DRIVE_RIGHT; SOT-23-6
U42: SPDT_PWM_MUX_PWM_WEAPON_FR; SOT-23-6
U43: SPDT_PWM_MUX_PWM_WEAPON_LR; SOT-23-6

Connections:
ADC_RX_6V: J48.3, R44.2, R45.1, TP12.1, U10.17
ADC_SERVO_6V: J48.2, R42.2, R43.1, TP11.1, U10.16
ADC_VBAT: J48.1, R40.2, R41.1, TP10.1, U10.15
AUX_3V3: C10.1, C11.1, C30.1, C31.1, J12.2, J46.2, J49.2, R10.1, R11.1, R46.1, R47.1, R50.1, R51.1, R52.1, SW1.2, TP6.1, U10.2, U30.4, U40.6, U41.6, U42.6, U43.6
AUX_3V3_SHDN: J46.4, U30.1
BUCK6_PG: J46.3, U20.5
CRSF_RX_FROM_RX: J11.3, J44.6, J46.6, U10.36
CRSF_TX_TO_RX: J11.4, J44.5, J46.5, U10.37
ESP_BOOT: J12.6, R11.2, SW3.1, U10.25
ESP_EN: J12.5, R10.2, SW2.1, U10.3
GND_PWR: C1.2, C2.2, C10.2, C11.2, C20.2, C21.2, C22.2, C23.2, C30.2, C31.2, D1.2, D2.2, J1.2, J10.1, J11.1, J12.1, J20.2, J21.1, J30.1, J31.1, J32.1, J33.1, J44.2, J46.1, J49.1, R41.2, R43.2, R45.2, SW2.2, SW3.2, TP3.1, U10.1, U10.38, U10.39, U10.40, U10.41, U20.2, U30.3, U40.2, U41.2, U42.2, U43.2
I2C_SCL: J47.2, J49.4, R47.2, U10.9
I2C_SDA: J47.1, J49.3, R46.2, U10.8
MCU_PWM_DRIVE_LEFT: U10.4, U40.3
MCU_PWM_DRIVE_RIGHT: U10.5, U41.3
MCU_PWM_WEAPON_FR: U10.6, U42.3
MCU_PWM_WEAPON_LR: U10.7, U43.3
MODE_MCU_CONTROL: SW1.4, TP9.1, U10.20, U40.5, U41.5, U42.5, U43.5
MODE_RX_DIRECT: SW1.3, TP8.1, U10.19
MODE_SAFE: SW1.1, TP7.1, U10.18
PWM_DRIVE_LEFT: J21.3, J47.3, TP13.1, U40.4
PWM_DRIVE_RIGHT: J21.4, J47.4, TP14.1, U41.4
PWM_WEAPON_FR: J30.3, J47.5, TP15.1, U42.4
PWM_WEAPON_LR: J31.3, J47.6, TP16.1, U43.4
PWR_LED_A: D2.1, R1.2
RX_6V: C23.1, FB1.2, J10.2, J11.2, J44.4, R44.1, TP5.1
RX_PWM_DRIVE_LEFT: J10.3, U40.1
RX_PWM_DRIVE_RIGHT: J10.4, U41.1
RX_PWM_WEAPON_FR: J10.5, U42.1
RX_PWM_WEAPON_LR: J10.6, U43.1
SERVO_6V: C20.1, C21.1, C22.1, FB1.1, J30.2, J31.2, J32.2, J33.2, J44.3, R42.1, TP4.1, U20.3
STATUS_LED_B_A: D52.1, R52.2
STATUS_LED_B_N: D52.2, J48.6, U10.12
STATUS_LED_G_A: D51.1, R51.2
STATUS_LED_G_N: D51.2, J48.5, U10.11
STATUS_LED_R_A: D50.1, R50.2
STATUS_LED_R_N: D50.2, J48.4, U10.10
UART0_RXD: J12.4, U10.34
UART0_TXD: J12.3, U10.35
VBAT_RAW: J1.1, J2.1, TP1.1
VBAT_SW: C1.1, C2.1, D1.1, F1.1, J2.2, J20.1, J44.1, R1.1, R40.1, TP2.1, U20.1
VBAT_SW_FUSED: F1.2, U30.2

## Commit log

2026-04-18 Enhance BATTLE_BOT1.md with detailed design recommendations for a 1 lb control flipper, emphasizing weight optimization, weapon configuration, and drive system improvements. Update README.md to clari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
2026-04-19 Update documentation to include mechanical CAD setup instructions and enhance KiCad workflow guidelines. Add local Python virtual environment entries to .gitignore and configure MCP for CAD operation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
    [battery_envelope.step, chassis_envelope.step, chassis_envelope.stl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]
2026-05-09 Update README.md to clarify current scripts for generating layouts and add instructions for viewing in FreeCAD. Enhance BOM.md with optional electrical growth parts and their specifications for futur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
    [00_system_overview.kicad_sch, 01_battery_safety.kicad_sch, 02_power_rails.kicad_sch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]
2026-05-09 Enhance KiCad project configuration by adding detailed design settings, including default parameters, rule severities, and teardrop options. Update track widths and via dimensions for improved layout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
    [flipping-cool.kicad_pcb]
2026-05-09 Refactor KiCad PCB design by reorganizing net connections, adding a new mounting hole footprint, and updating existing footprints for resistors and test points. Adjust design rules in the project con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
    [flipping-cool.kicad_pcb]
2026-05-09 Update KiCad PCB design by renaming footprints for resistors, capacitors, connectors, and test points to include component categories. Adjust footprint positions for improved layout accuracy and cons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
    [flipping-cool-B_Cu.gbr, flipping-cool-B_Mask.gbr, flipping-cool-B_Paste.gbr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]
2026-05-09 Refactor Flipping Cool PCB design to Rev B, integrating active electrical features including ESP32-S3 module, power management, and control authority. Update documentation to reflect new architecture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
    [flipping-cool-B_Courtyard.gbr, flipping-cool-B_Cu.gbl, flipping-cool-B_Fab.gbr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]
2026-05-09 Refactor Flipping Cool PCB design to Rev B, updating title, date, and revision details. Integrate ESP32-S3 module and enhance documentation for MCU I/O and debugging features, while maintaining histo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
    [00_system_overview.kicad_sch, 01_battery_safety.kicad_sch, 02_power_rails.kicad_sch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]
2026-05-09 Remove obsolete Flipping Cool Rev B project plan file and update schematic files to reflect the latest design changes, including integration of the ESP32-S3 module and enhancements to power managemen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
    [01_battery_safety.kicad_sch, 02_power_rails.kicad_sch, 03_receiver_pwm.kicad_sch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]
